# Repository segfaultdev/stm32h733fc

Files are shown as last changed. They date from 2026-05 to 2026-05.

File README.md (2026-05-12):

# STM32H733VGT6 Flight Controller

## Overview

This repository contains the hardware documentation and pinout routing for a custom flight controller based on the STM32H733VGT6 microcontroller. Designed for high-performance flight dynamics, this board leverages the MCU's 550 MHz clock speed, math coprocessor, and extensive I/O capabilities.

---

## Current Pinout & Peripheral Mapping

Below is the structured peripheral documentation based on the current schematic routing.

### 1. Serial Peripheral Interface (SPI)

*Primarily used for high-speed sensors (IMU), OSD chips, Blackbox Flash memory, and SD Cards.*

| Peripheral | Pins | Typical Signal Mapping | Suggested Use Case |
| :--- | :--- | :--- | :--- |
| **SPI1** | PA4 - PA7 | PA4 (NSS), PA5 (SCK), PA6 (MISO), PA7 (MOSI) | **Primary IMU** (e.g., MPU6000, BMI270) |
| **SPI2** | PB12 - PB15 | PB12 (NSS), PB13 (SCK), PB14 (MISO), PB15 (MOSI) | **Secondary IMU** or **OSD** (AT7456E) |
| **SPI3** | PA15, PC10 - PC12 | PA15 (NSS), PC10 (SCK), PC11 (MISO), PC12 (MOSI) | **Blackbox Flash** (e.g., W25Q128) |
| **SPI4** | PE11 - PE14 | PE11 (NSS), PE12 (SCK), PE13 (MISO), PE14 (MOSI) | **SD Card** or **Third IMU** |

### 2. Inter-Integrated Circuit (I2C)

*Used for slower, address-based peripherals like Barometers and Compasses.*

| Peripheral | Pins | Signal Mapping | Suggested Use Case |
| :--- | :--- | :--- | :--- |
| **I2C1** | PB6 - PB7 | PB6 (SCL), PB7 (SDA) | **Barometer** (e.g., BMP280, DPS310) |
| **I2C2** | PB10 - PB11 | PB10 (SCL), PB11 (SDA) | **Magnetometer/Compass** (e.g., QMC5883) |
| **I2C4** | PD12 - PD13 | PD12 (SCL), PD13 (SDA) | Breakout / I2C Expansion Pad |

### 3. Universal Asynchronous Receiver-Transmitter (UART)

*Used for external communications: Radio Receivers, GPS, Digital Video Transmitters, and Telemetry.*

| Peripheral | Pins | Signal Mapping | Suggested Use Case |
| :--- | :--- | :--- | :--- |
| **UART1**  | PA9 - PA10  | PA9 (TX), PA10 (RX)  | **Digital VTX** (DJI O3, Walksnail, HDZero) |
| **UART2**  | PA2 - PA3 | PA2 (TX), PA3 (RX) | **Radio Receiver** (ExpressLRS / Crossfire) |
| **UART3**  | PD8 - PD9 | PD8 (TX), PD9 (RX) | **GPS** (RX to GPS TX, TX to GPS RX) |
| **UART4**  | PA0 - PA1 | PA0 (TX), PA1 (RX) | **ESC Telemetry** (Usually RX only needed)  |
| **UART7**  | PE7 - PE8 | PE8 (TX), PE7 (RX) | Free Serial Port |
| **UART8**  | PE0 - PE1 | PE1 (TX), PE0 (RX) | Free Serial Port |
| **UART9**  | PD14 - PD15 | PD15 (TX), PD14 (RX) | Free Serial Port |
| **UART10** | PE2 - PE3 | PE3 (TX), PE2 (RX) | Free Serial Port |

### 4. Controller Area Network (CAN)

*Used for robust, high-speed communication with DroneCAN peripherals (smart ESCs, advanced GPS modules).*

| Peripheral | Pins | Signal Mapping | Suggested Use Case |
| :--- | :--- | :--- | :--- |
| **FDCAN1** | PB8 - PB9 | PB9 (TX), PB8 (RX) | **DroneCAN Peripheral Bus** |

### 5. Timers & Motor Outputs

*Used for sending DSHOT or PWM signals to the Electronic Speed Controllers (ESCs).*

| Peripheral | Pins | Signal Mapping | Suggested Use Case |
| :--- | :--- | :--- | :--- |
| **TIM8** | PC6 - PC9 | PC6 (CH1), PC7 (CH2), PC8 (CH3), PC9 (CH4) | **Motor 1-4 Outputs** (DSHOT/PWM) |

---

## Hardware Routing To-Do List

The following critical subsystems still need to be established to make the flight controller fully functional.

- [ ] **USB Communication:** Route `PA11` (USB_D-) and `PA12` (USB_D+) and design the USB-C connector circuit with 5.1k CC pull-down resistors.
- [ ] **Debug and Flashing (SWD):** Route `PA13` (SWDIO) and `PA14` (SWCLK) to dedicated debug pads.
- [ ] **Analog Inputs (ADC):** Select ADC-capable pins (like `PC1`, `PC2`, or `PC3`) and route them to the Voltage Divider circuit (VBAT) and Current Sensor amplifier output.
- [ ] **System Basics:**
  - [ ] **Buzzer:** Route a GPIO pin to a transistor circuit for a 5V active buzzer.
  - [ ] **Status LEDs:** Route 1 or 2 free GPIO pins to drive status LEDs.
  - [ ] **Addressable LED Strip:** Route a DMA-capable timer pin for WS2812B RGB LEDs.

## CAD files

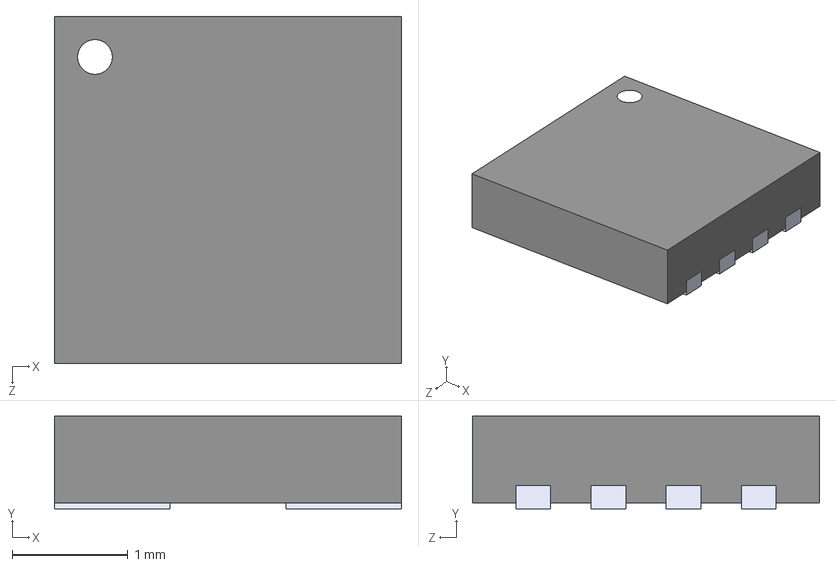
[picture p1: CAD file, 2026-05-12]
hardware/Components/MP9943GQ-Z.STEP
3.00 x 0.8 x 3.00 mm

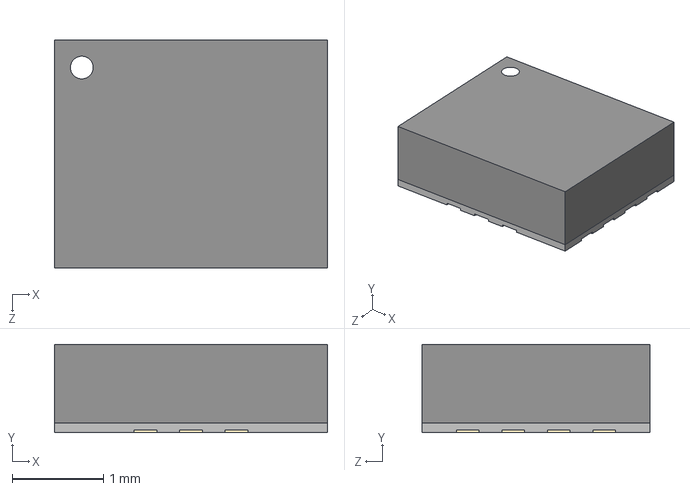
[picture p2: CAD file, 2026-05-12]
hardware/Components/ICM-42688-P--3DModel-STEP-1.STEP
3.00 x 0.97 x 2.50 mm

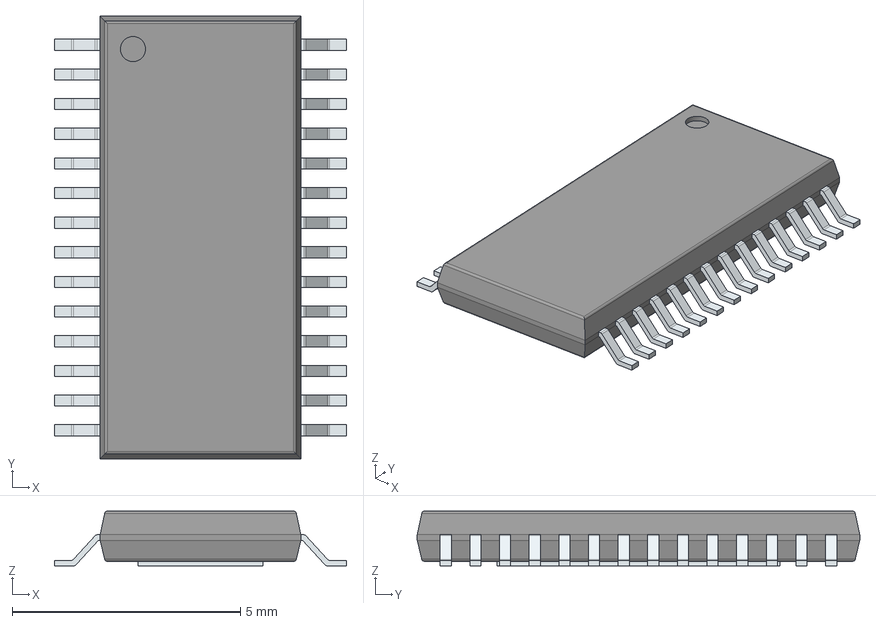
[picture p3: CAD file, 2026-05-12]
hardware/Components/AT7456E.stp
6.40 x 9.70 x 1.20 mm
PinsArrayLR
ThermalPad

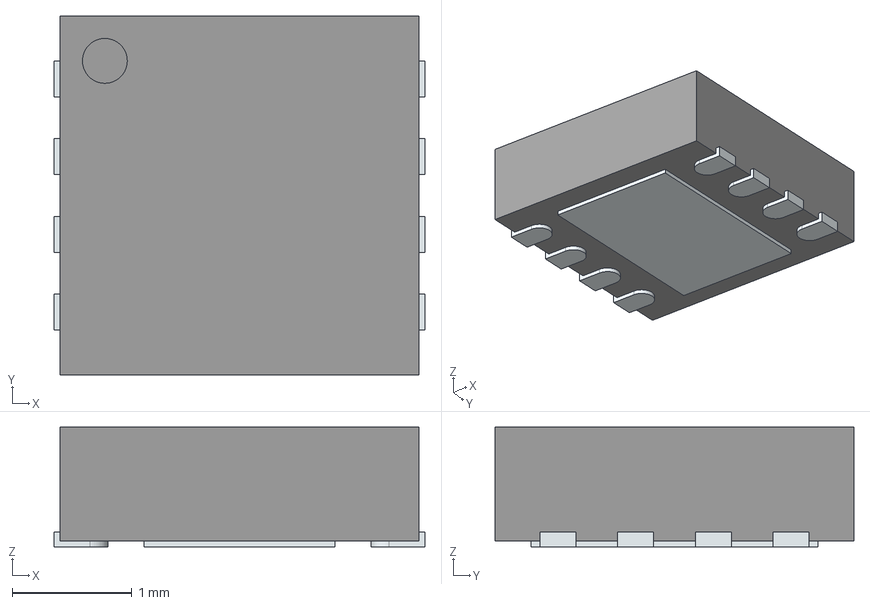
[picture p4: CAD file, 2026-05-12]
hardware/Components/TJA1051TK_3,118.stp
3.10 x 3.00 x 1.00 mm
ThermalPin
PinsArrayLR

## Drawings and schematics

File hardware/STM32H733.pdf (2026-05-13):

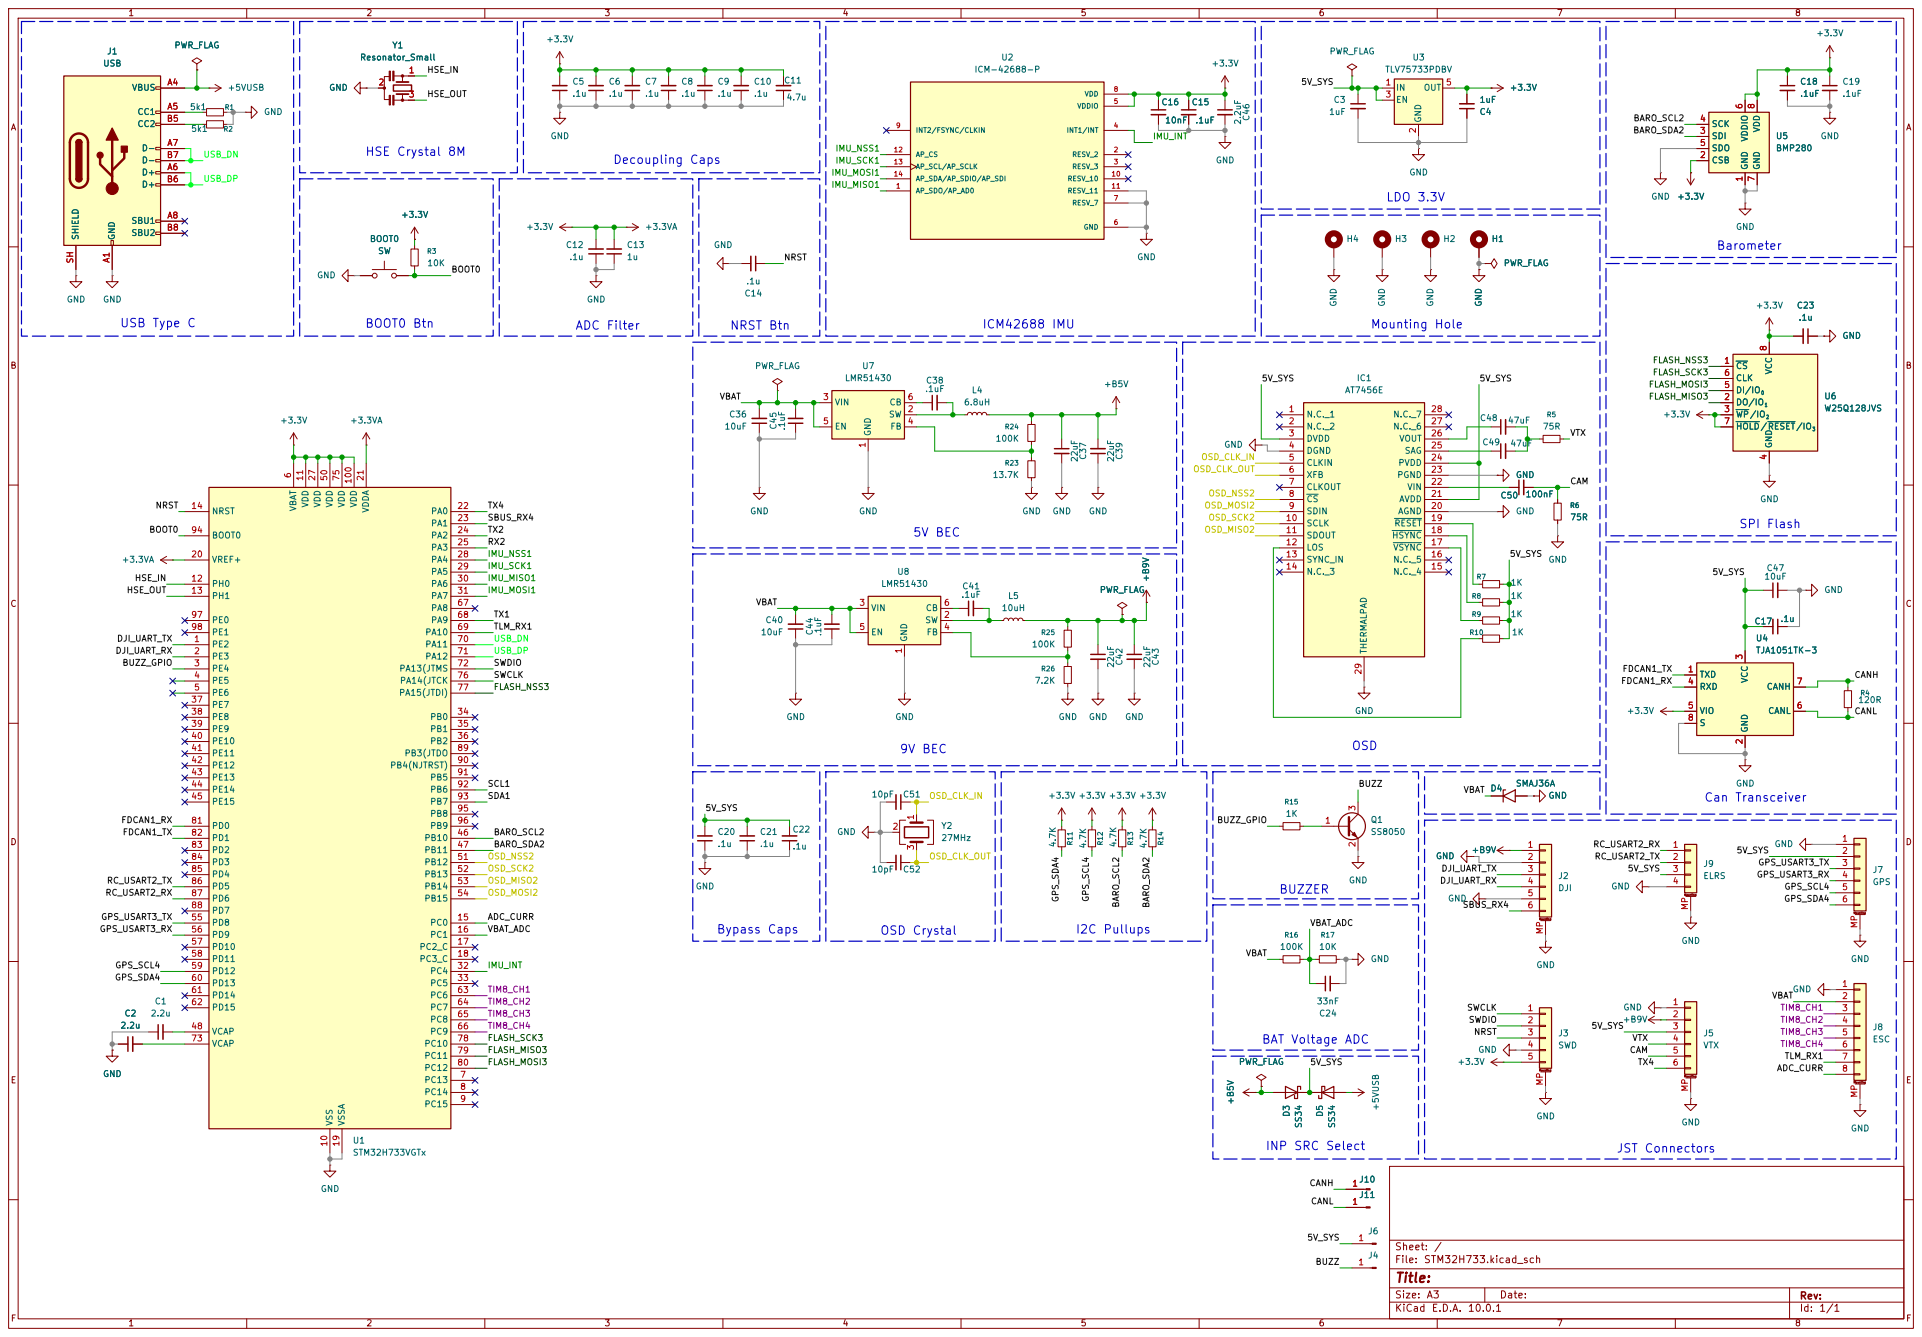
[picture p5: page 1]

5V_SYS | I2C Pullups | SS8050 GND

JST Connectors

Size: A3 | Rev: | F Date:
KiCad E.D.A. 10.0.1 | Id: 1/1

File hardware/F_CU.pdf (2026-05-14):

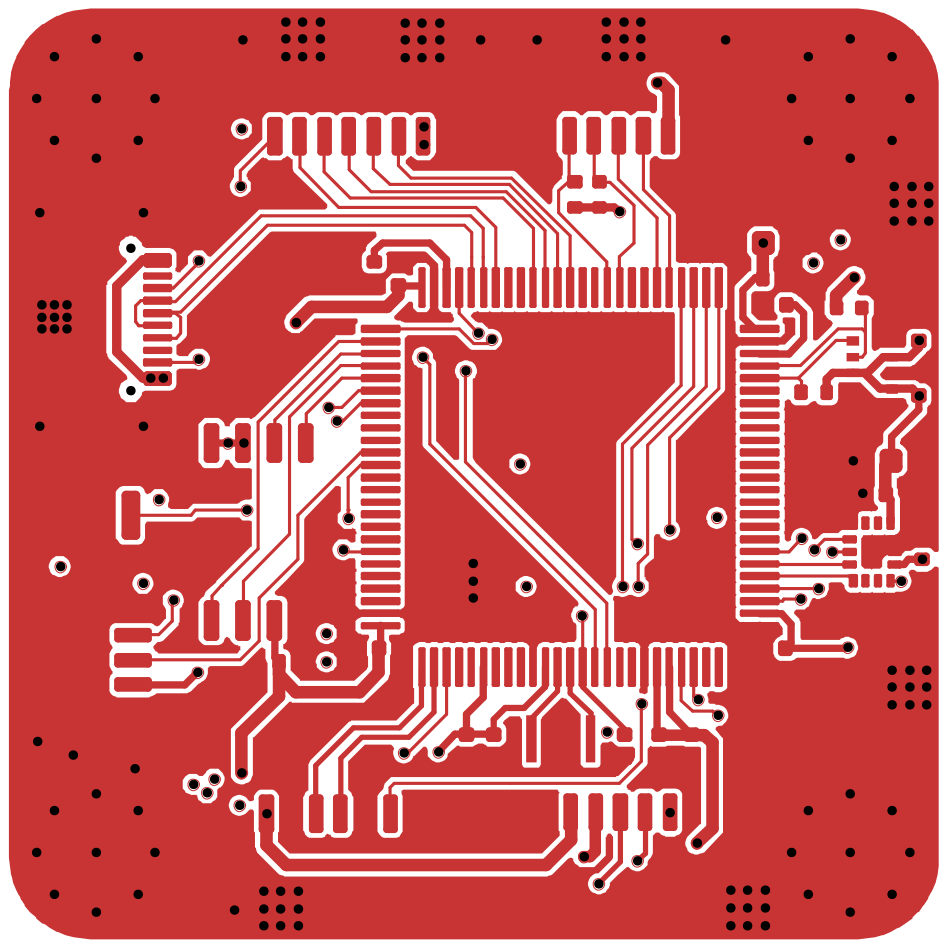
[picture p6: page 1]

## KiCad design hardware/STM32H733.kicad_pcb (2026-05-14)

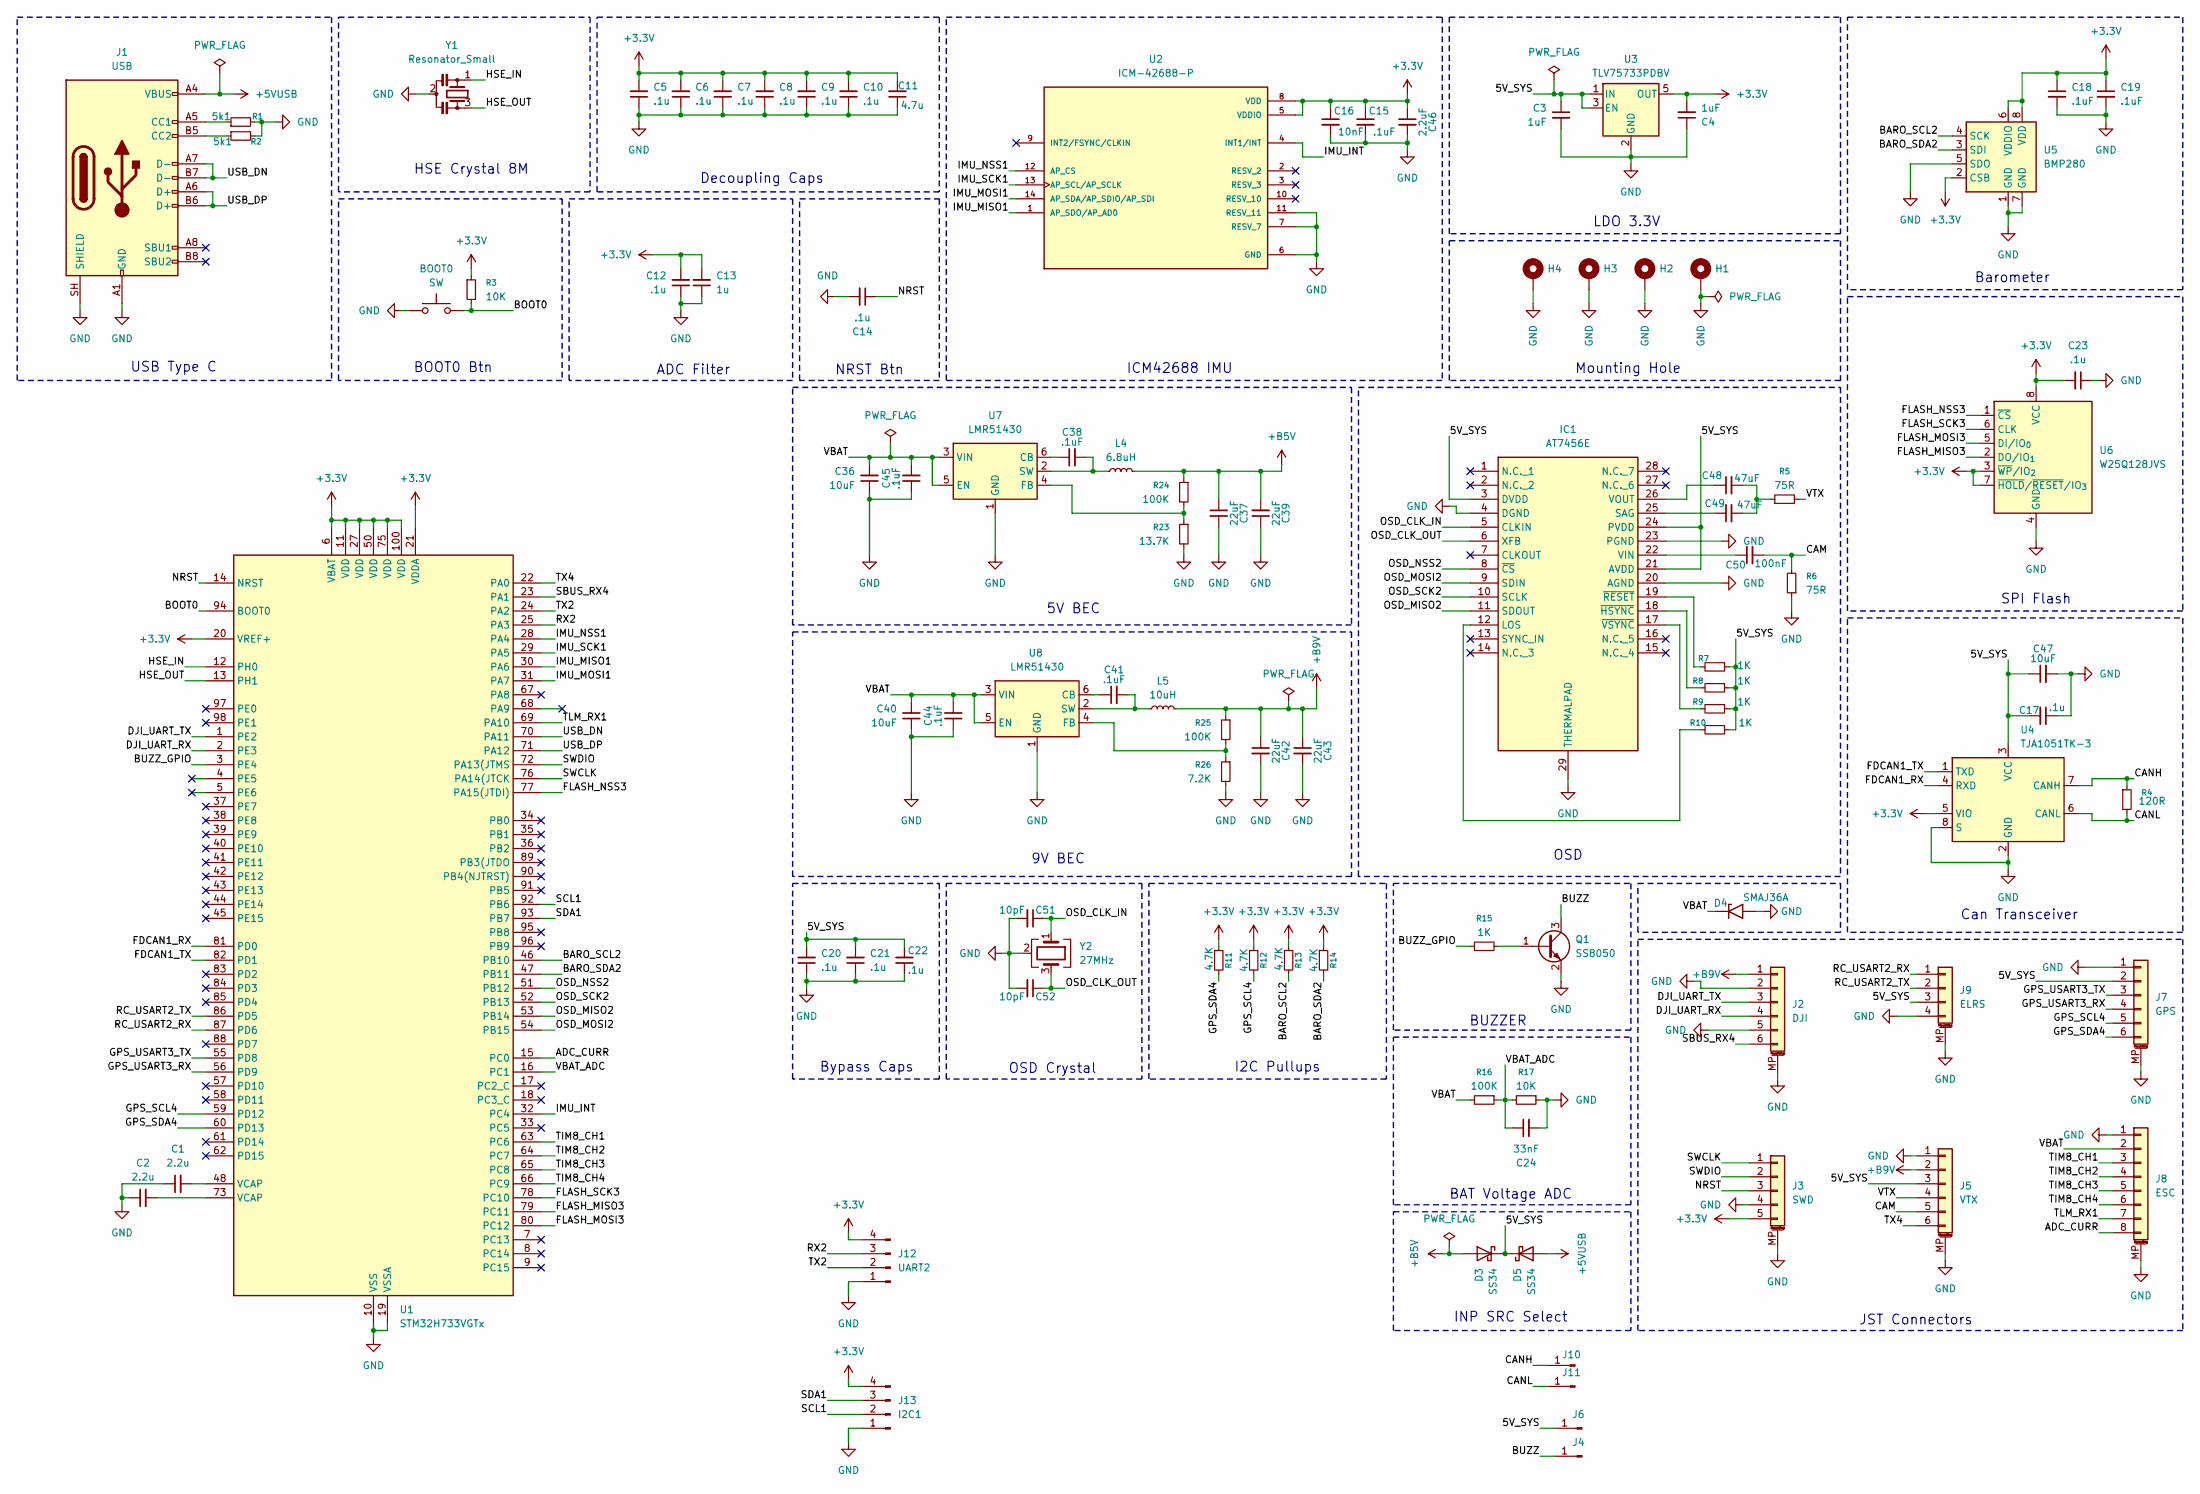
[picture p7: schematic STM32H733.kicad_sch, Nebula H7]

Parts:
BOOT0: SW; SW_Push_SPST_NO_Alps_SKRK
C1, C2: 2.2u; C_0402_1005Metric
C3, C4: 1uF; C_0603_1608Metric
C5, C6, C7, C8, C9, C10, C12, C14, C17, C20, C21, C22, C23: .1u; C_0402_1005Metric
C11: 4.7u; C_0603_1608Metric
C13: 1u; C_0402_1005Metric
C15, C18, C19: .1uF; C_0402_1005Metric
C16: 10nF; C_0402_1005Metric
C24: 33nF; C_0402_1005Metric
C36, C40, C47: 10uF; C_0805_2012Metric
C37, C39, C42, C43: 22uF; C_0805_2012Metric
C38, C41, C44, C45: .1uF; C_0603_1608Metric
C46: 2.2uF; C_0603_1608Metric
C48, C49: 47uF; CP_EIA-3216-18_Kemet-A
C50: 100nF; C_0402_1005Metric
C51, C52: 10pF; C_0402_1005Metric
D3, D5: SS34; D_SMA
D4: SMAJ36A; D_SMA
H1, H2, H3, H4: MountingHole_Pad; MountingHole_3.2mm_M3_Pad_Via
IC1: AT7456E; SOP65P640X120-29N; Manufacturer_Part_Number AT7456E
J1: USB; USB_C_Receptacle_GCT_USB4105-xx-A_16P_TopMnt_Horizontal
J2: DJI; JST_SH_SM06B-SRSS-TB_1x06-1MP_P1.00mm_Horizontal
J3: SWD; JST_SH_SM05B-SRSS-TB_1x05-1MP_P1.00mm_Horizontal
J4, J6: Conn_01x01_Pin; TestPoint_Pad_1.5x1.5mm
J5: VTX; JST_SH_SM06B-SRSS-TB_1x06-1MP_P1.00mm_Horizontal
J7: GPS; JST_SH_SM06B-SRSS-TB_1x06-1MP_P1.00mm_Horizontal
J8: ESC; JST_SH_SM08B-SRSS-TB_1x08-1MP_P1.00mm_Horizontal
J9: ELRS; JST_SH_SM04B-SRSS-TB_1x04-1MP_P1.00mm_Horizontal
J10: CH; TestPoint_Pad_1.0x1.0mm
J11: CL; TestPoint_Pad_1.0x1.0mm
J12: UART2; ConnPadx04
J13: I2C1; ConnPadx04
L4: 6.8uH; L_Changjiang_FXL0420
L5: 10uH; L_Changjiang_FXL0420
Q1: SS8050; SOT-23
R1, R2: 5k1; R_0402_1005Metric
R3, R17: 10K; R_0402_1005Metric
R4: 120R; R_0402_1005Metric
R5, R6: 75R; R_0402_1005Metric
R7, R8, R9, R10, R15: 1K; R_0402_1005Metric
R11, R12, R13, R14: 4.7K; R_0402_1005Metric
R16, R24, R25: 100K; R_0402_1005Metric
R23: 13.7K; R_0402_1005Metric
R26: 7.2K; R_0402_1005Metric
U1: STM32H733VGTx; LQFP-100_14x14mm_P0.5mm
U2: ICM-42688-P; PQFN50P300X250X97-14N; PARTREV 1.2
U3: TLV75733PDBV; SOT-23-5
U4: TJA1051TK-3; HVSON-8-1EP_3x3mm_P0.65mm_EP1.6x2.4mm
U5: BMP280; Bosch_LGA-8_2x2.5mm_P0.65mm_ClockwisePinNumbering
U6: W25Q128JVS; SOIC-8_5.3x5.3mm_P1.27mm
U7, U8: LMR51430; SOT-23-6
Y1: Resonator_Small; Resonator_SMD_Murata_CSTxExxV-3Pin_3.0x1.1mm
Y2: 27MHz; Crystal_SMD_3225-4Pin_3.2x2.5mm

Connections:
+3.3V: C4.2, C5.2, C6.2, C7.2, C8.2, C9.2, C10.2, C11.2, C12.2, C13.2, C15.1, C16.1, C18.1, C19.1, C23.2, C46.1, J3.5, J12.4, J13.4, R3.1, R11.1, R12.1, R13.1, R14.1, U1.6 (VBAT), U1.11 (VDD), U1.20 (VREF+), U1.21 (VDDA), U1.27 (VDD), U1.50 (VDD), U1.75 (VDD), U1.100 (VDD), U2.5 (VDDIO), U2.8 (VDD), U3.5 (OUT), U4.5 (VIO), U5.2 (CSB), U5.6 (VDDIO), U5.8 (VDD), U6.3 (~WP/IO_{2}), U6.7 (~HOLD/~RESET/IO_{3}), U6.8 (VCC)
+5VUSB: D5.2 (A), J1.A4 (VBUS), J1.A9 (VBUS), J1.B4 (VBUS), J1.B9 (VBUS)
+B5V: C37.1, C39.2, D3.2 (A), L4.2, R24.1
+B9V: C42.1, C43.1, J2.1, J5.2, L5.2, R25.1
/5V_SYS: C3.1, C17.2, C20.2, C21.2, C22.2, C47.1, D3.1 (K), D5.1 (K), IC1.3 (DVDD), IC1.21 (AVDD), IC1.24 (PVDD), J5.3, J6.1 (Pin_1_1), J7.2, J9.3, R7.1, R8.1, R9.1, R10.1, U3.1 (IN), U3.3 (EN), U4.3 (VCC)
/ADC_CURR: J8.8, U1.15 (PC0)
/BARO_SCL2: R13.2, U1.46 (PB10), U5.4 (SCK)
/BARO_SDA2: R14.2, U1.47 (PB11), U5.3 (SDI)
/BOOT0: BOOT0.2, R3.2, U1.94 (BOOT0)
/BUZZ: J4.1 (Pin_1_1), Q1.3 (C)
/BUZZ_GPIO: R15.1, U1.3 (PE4)
/CAM: C50.2, J5.5, R6.2
/CANH: J10.1 (Pin_1_1), R4.1, U4.7 (CANH)
/CANL: J11.1 (Pin_1_1), R4.2, U4.6 (CANL)
/DJI_UART_RX: J2.4, U1.2 (PE3)
/DJI_UART_TX: J2.3, U1.1 (PE2)
/FDCAN1_RX: U1.81 (PD0), U4.4 (RXD)
/FDCAN1_TX: U1.82 (PD1), U4.1 (TXD)
/FLASH_MISO3: U1.79 (PC11), U6.2 (DO/IO_{1})
/FLASH_MOSI3: U1.80 (PC12), U6.5 (DI/IO_{0})
/FLASH_NSS3: U1.77 (PA15(JTDI)), U6.1 (~CS)
/FLASH_SCK3: U1.78 (PC10), U6.6 (CLK)
/GPS_SCL4: J7.5, R12.2, U1.59 (PD12)
/GPS_SDA4: J7.6, R11.2, U1.60 (PD13)
/GPS_USART3_RX: J7.4, U1.56 (PD9)
/GPS_USART3_TX: J7.3, U1.55 (PD8)
/HSE_IN: U1.12 (PH0), Y1.1
/HSE_OUT: U1.13 (PH1), Y1.3
/IMU_INT: U1.32 (PC4), U2.4 (INT1/INT)
/IMU_MISO1: U1.30 (PA6), U2.1 (AP_SDO/AP_AD0)
/IMU_MOSI1: U1.31 (PA7), U2.14 (AP_SDA/AP_SDIO/AP_SDI)
/IMU_NSS1: U1.28 (PA4), U2.12 (AP_CS)
/IMU_SCK1: U1.29 (PA5), U2.13 (AP_SCL/AP_SCLK)
/NRST: C14.1, J3.3, U1.14 (NRST)
/OSD_CLK_IN: C51.1, IC1.5 (CLKIN), Y2.1
/OSD_CLK_OUT: C52.1, IC1.6 (XFB), Y2.3
/OSD_MISO2: IC1.11 (SDOUT), U1.53 (PB14)
/OSD_MOSI2: IC1.9 (SDIN), U1.54 (PB15)
/OSD_NSS2: IC1.8 (~CS), U1.51 (PB12)
/OSD_SCK2: IC1.10 (SCLK), U1.52 (PB13)
/RC_USART2_RX: J9.1, U1.87 (PD6)
/RC_USART2_TX: J9.2, U1.86 (PD5)
/RX2: J12.3, U1.25 (PA3)
/SBUS_RX4: J2.6, U1.23 (PA1)
/SCL1: J13.2, U1.92 (PB6)
/SDA1: J13.3, U1.93 (PB7)
/SWCLK: J3.1, U1.76 (PA14(JTCK)
/SWDIO: J3.2, U1.72 (PA13(JTMS)
/TIM8_CH1: J8.3, U1.63 (PC6)
/TIM8_CH2: J8.4, U1.64 (PC7)
/TIM8_CH3: J8.5, U1.65 (PC8)
/TIM8_CH4: J8.6, U1.66 (PC9)
/TLM_RX1: J8.7, U1.69 (PA10)
/TX1: U1.68 (PA9)
/TX2: J12.2, U1.24 (PA2)
/TX4: J5.6, U1.22 (PA0)
/USB_DN: J1.A7 (D-), J1.B7 (D-), U1.70 (PA11)
/USB_DP: J1.A6 (D+), J1.B6 (D+), U1.71 (PA12)
/VBAT: C36.2, C40.2, C44.2, C45.2, D4.1 (A1), J8.2, R16.2, U7.3 (VIN), U7.5 (EN), U8.3 (VIN), U8.5 (EN)
/VBAT_ADC: C24.1, R16.1, R17.2, U1.16 (PC1)
/VTX: J5.4, R5.2
GND: BOOT0.1, C1.1, C2.1, C3.2, C4.1, C5.1, C6.1, C7.1, C8.1, C9.1, C10.1, C11.1, C12.1, C13.1, C14.2, C15.2, C16.2, C17.1, C18.2, C19.2, C20.1, C21.1, C22.1, C23.1, C24.2, C36.1, C37.2, C39.1, C40.1, C42.2, C43.2, C44.1, C45.1, C46.2, C47.2, C51.2, C52.2, D4.2 (A2), H1.1 (1_1), H2.1 (1_1), H3.1 (1_1), H4.1 (1_1), IC1.4 (DGND), IC1.20 (AGND), IC1.23 (PGND), IC1.29 (THERMALPAD), J1.A1 (GND), J1.A12 (GND), J1.B1 (GND), J1.B12 (GND), J1.SH (SHIELD), J2.2, J2.5, J2.MP (MountPin), J3.4, J3.MP (MountPin), J5.1, J5.MP (MountPin), J7.1, J7.MP (MountPin), J8.1, J8.MP (MountPin), J9.4, J9.MP (MountPin), J12.1, J13.1, Q1.2 (E), R1.2, R2.2, R6.1, R17.1, R23.2, R26.2, U1.10 (VSS), U1.19 (VSSA), U1.26 (VSS), U1.49 (VSS), U1.74 (VSS), U1.99 (VSS), U2.6 (GND), U2.7 (RESV_7), U2.11 (RESV_11), U3.2 (GND), U4.2 (GND), U4.8 (S), U4.9 (GND), U5.1 (GND), U5.5 (SDO), U5.7 (GND), U6.4 (GND), U7.1 (GND), U8.1 (GND), Y1.2, Y2.2 (G), Y2.4 (G)
unnamed: C1.2, U1.48 (VCAP)
unnamed: C2.2, U1.73 (VCAP)
unnamed: C48.2, C49.2, R5.1
unnamed: IC1.12 (LOS), R10.2
unnamed: C49.1, IC1.25 (SAG)
unnamed: C50.1, IC1.22 (VIN)
unnamed: C48.1, IC1.26 (VOUT)
unnamed: IC1.18 (~HSYNC), R8.2
unnamed: IC1.19 (~RESET), R7.2
unnamed: IC1.17 (~VSYNC), R9.2
unnamed: J1.A5 (CC1), R1.1
unnamed: J1.B5 (CC2), R2.1
unnamed: Q1.1 (B), R15.2
unnamed: C38.1, U7.6 (CB)
unnamed: R23.1, R24.2, U7.4 (FB)
unnamed: C38.2, L4.1, U7.2 (SW)
unnamed: C41.1, U8.6 (CB)
unnamed: R25.2, R26.1, U8.4 (FB)
unnamed: C41.2, L5.1, U8.2 (SW)

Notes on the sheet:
HSE Crystal 8M
Can Transceiver
INP SRC Select
OSD
SPI Flash
BUZZER
ICM42688 IMU
NRST Btn
Bypass Caps
ADC Filter
USB Type C
Barometer
5V BEC
I2C Pullups
BAT Voltage ADC
Decoupling Caps
OSD Crystal
9V BEC
LDO 3.3V
JST Connectors
Mounting Hole
BOOT0 Btn

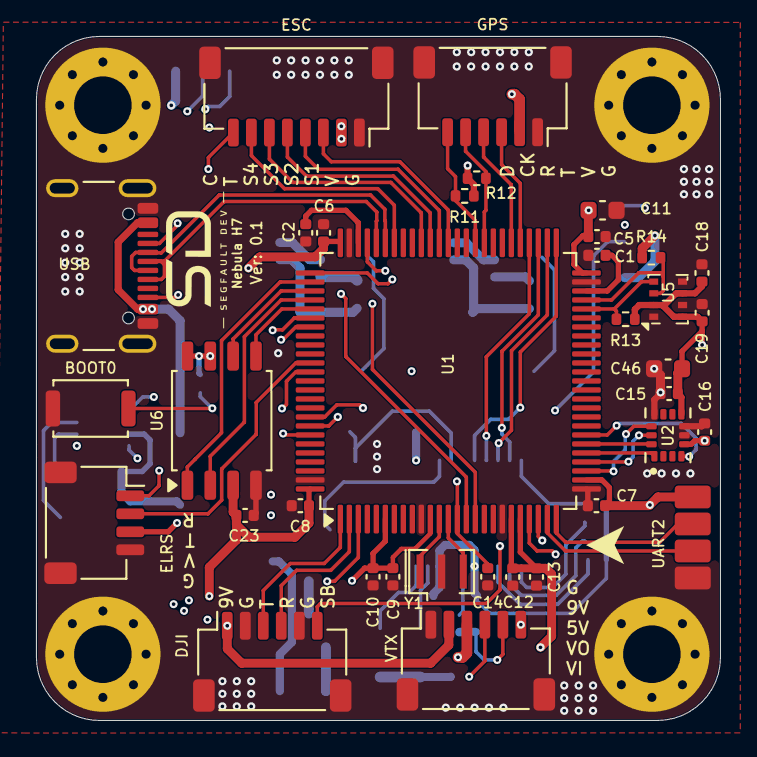
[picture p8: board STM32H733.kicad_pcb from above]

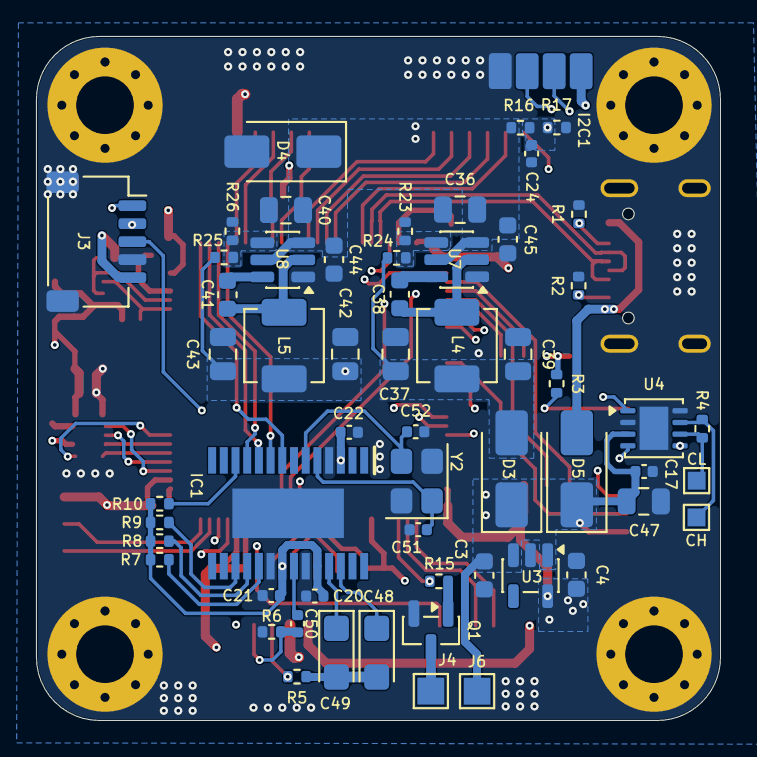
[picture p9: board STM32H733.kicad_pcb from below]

Board: 4 copper layers, 38.0 x 38.0 mm, 97 parts (58 on the bottom side), 80 nets.

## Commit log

2026-05-12 New Directory Structure
    [AT7456E.stp, ICM-42688-P--3DModel-STEP-1.STEP, MP9943GQ-Z.STEP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]
2026-05-12 Mostly Done. Need to Fix some Warnings, Need to add Soldering Pad for
    CANH and CANL, need to add few pads for UART, I2C, SPI for future use
    Need some Test Pads for power
    [STM32H733.kicad_pcb]
2026-05-13 Flight Controller:
    Almost Done With the PCB design Except the Leds
    and Few Peripherals Pad for external Sensors
    and modules
    [STM32H733.kicad_pcb, STM32H733.kicad_sch]
2026-05-14 Nebula H7: V 0.1
    need to add some indicator led
    [STM32H733.kicad_pcb, STM32H733.kicad_sch, freerouting.dsn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]
